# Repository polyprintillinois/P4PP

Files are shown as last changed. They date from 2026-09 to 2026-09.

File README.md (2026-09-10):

<div align="center">
  P4PP Logo
  <h1>P4PP</h1>
  <p><b>Precision 4-Point Probe Controller</b></p>
  <p>Windows GUI for operating a 4-point probe system and logging sheet resistance measurements.</p>
</div>

This repository accompanies **Hwang, Elangovan, Damron, Kwok, Jeon & Diao, "Democratizing Lab Automation through Multi-Agent-Assisted Design and 3D Printing"** (submitted, 2026). Archived release: Zenodo DOI [10.5281/zenodo.22695915](https://doi.org/10.5281/zenodo.22695915). Code is released under the MIT licence; printed-part designs (STL) and documentation may be reused under the same terms with attribution.

---

## Overview

P4PP is the control application for a custom 4-point probe measurement setup.

It provides:

- motion and hardware control through serial communication
- measurement execution (single or multi-cycle)
- live result visualization
- automatic CSV reporting

Target metric: **Sheet Resistance (Rs, Ohm/sq)**.

## Quick Start (1 Minute)

1. Download latest release: https://github.com/polyprintillinois/P4PP/releases/latest
2. In release assets, download `P4PP.zip`.
3. Extract to a stable folder (example: `C:\Tools\P4PP`).
4. Open extracted `P4PP` folder and run `P4PP.exe`.
5. In the app, keep the default `R_set = 681 ohm`, then select `MOCK` and validate `Connect -> Home -> Measure`.

Important:

- Keep the extracted `P4PP` folder structure as-is.
- Do not move `P4PP.exe` outside the `P4PP` folder.

## First run (hello world)

1. For real hardware, flash `firmware/p4pp_firmware/p4pp_firmware.ino` to the Arduino Nano 33 IoT. Connect the 12 V / 60 W adapter (relay coil and stepper drivers) and the USB cable (logic and 3.3 V analog rail).
2. Launch the GUI (`P4PP.zip` from Releases, or `python main.py`) and connect. Without hardware, select `MOCK` in the port list and click **Connect**; this runs the GUI against `src/p4pp/driver/mock_hardware.py`. Click **Initialize**, leave the geometry at **Infinite Sheet**, and click **Measure**. The expected synthetic result is approximately 687 Ω/sq.
3. With real hardware, select the Arduino COM port and click **Connect**. Click **HOME** for both axes (Z probe lift and θ sample rotation), or click **Initialize** to home them in sequence. Each axis should complete a fast switch seek, back-off, and slow re-approach.
4. Insert the 68.1 Ω set resistor (approximately 1 mA), place a reference sample of known sheet resistance (for example, ITO-coated glass), select the sample geometry, and click **Measure**. One delta-mode cycle takes approximately 0.3 s; five cycles are averaged by default (up to 20 may be selected).
5. The reported sheet resistance should fall within `0.90 × R_ref` to `1.10 × R_ref` (the approximately 10% agreement obtained against a commercial four-point-probe system in the paper), with a cycle-to-cycle CV below 0.1%. Re-landing the probe on the same spot should reproduce the value within approximately 2%.
6. Swap in the 681 Ω set resistor (approximately 100 µA) for samples in the kΩ/sq range.

If readings are physically implausible (negative, or identical for forward and reverse polarity), check the DPDT relay wiring: both poles must switch. See the [Analog Wiring Guide](docs/analog_wiring_guide.md).

## Safety

- The probe head descends with approximately 3.3 N total tip force (85 gf × 4) and has sharp tungsten tips. Keep fingers clear of the sample stage while the Z axis is moving, and never reach under the probe head.
- 12 V is present on the driver and relay board; the analog section runs from the 3.3 V rail. Disconnect the adapter before rewiring.
- Do not touch the sample or probe during a measurement cycle. The relay reverses current polarity within each cycle, and contact changes corrupt the reading.
- Handle doped polymer films and dopant solutions (for example, Magic Blue in acetonitrile) with gloves in a fume hood. The instrument itself does not contain solvents.

## App Screenshot

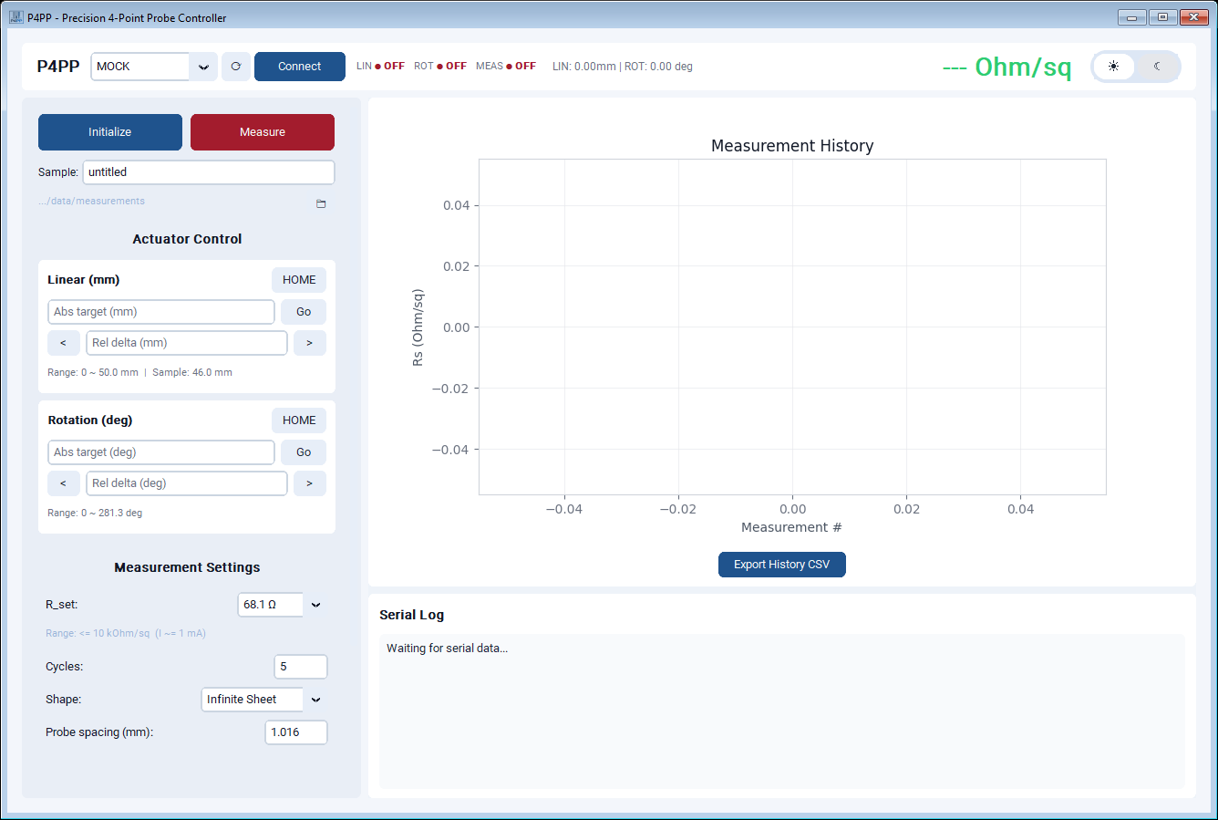
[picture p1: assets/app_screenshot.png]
P4PP main window screenshot


## Highlights

- Live GUI for connect/home/move/measure workflow
- `MOCK` mode for validation without hardware
- Real-time status + graph updates
- Auto-save per-measurement CSV reports
- History CSV export
- Explicit controller state handling

## Hardware Bring-Up (Real Device)

Before using real hardware:

1. Flash firmware: `firmware/p4pp_firmware/p4pp_firmware.ino`
2. Confirm COM port in Windows Device Manager.
3. Complete wiring and calibration checks in docs below.

`R_set` guidance:

- Default startup mode is `681 ohm` (`~0.1 mA`), which is the safer general-purpose option for initial bring-up.
- Switch to `68.1 ohm` (`~1 mA`) for lower-resistance samples such as ITO when you need stronger signal.

Read docs in this order:

1. [4PP Master Guide](docs/4pp_master_guide.md)
2. [Analog Wiring Guide](docs/analog_wiring_guide.md)
3. [Movement Implementation Guide](docs/movement_implementation_guide.md)
4. [App Architecture](docs/app_architecture.md)

## First Real Measurement Checklist

1. Pass full `MOCK` workflow first.
2. Switch to real COM port and connect.
3. Run one low-risk test sample.
4. Confirm graph updates and CSV output in `data/`.

## Troubleshooting

### Serial connection fails

- Recheck COM port in Device Manager.
- Ensure no other application is holding the port.
- Re-test with `MOCK` mode first.

### App does not start (`ModuleNotFoundError: tkinter`)

- Use the official release package (`P4PP.zip`) from Releases.
- If you built locally, use Python 3.11 and rebuild with `P4PP.spec`.

### Measured result stays near `0.00`

- Confirm the Arduino firmware is updated together with the PC app.
- `681 ohm` mode is intended for higher-resistance samples; low-resistance films may require `68.1 ohm`.

### Build/runtime metadata error (`PackageNotFoundError: p4pp`)

- Build with `main.py` as entry script.
- Use the provided `P4PP.spec`.

### Build instability on mixed Python environments

- Build using a clean Python 3.11 virtual environment.
- Clear `PYTHONPATH` before packaging to avoid external site-package contamination.

---

## Developer Notes

### Repository Structure

```text
P4PP/
|- assets/               # logo/icons
|- data/                 # measurement outputs
|- docs/                 # English docs
|- firmware/             # Arduino firmware
|- src/p4pp/             # application source
|- main.py               # app entry point
|- P4PP.spec             # PyInstaller spec
`- setup.py              # package metadata
```

### Local Run

```powershell
py -3.11 -m venv venv
.\venv\Scripts\Activate.ps1
python -m pip install --upgrade pip
pip install -e .
python main.py
```

### Build

```powershell
py -3.11 -m venv build_venv
.\build_venv\Scripts\Activate.ps1
python -m pip install --upgrade pip
python -m pip install pyserial customtkinter matplotlib Pillow pyinstaller
$env:PYTHONPATH = ""
python -m PyInstaller --noconfirm --clean P4PP.spec
```

Output:

- `dist/P4PP/P4PP.exe`
- optional archive: `dist/P4PP.zip`

## Distribution Policy

- `dist/` is **not tracked** in `main` (ignored by `.gitignore`).
- Binaries are distributed via **GitHub Releases assets**.
- `build/` is temporary and can be deleted safely.

## License

P4PP is released under the [MIT License](LICENSE).

Copyright (c) 2026 Changhyun Hwang, Diao Research Group, University of Illinois at Urbana-Champaign.

Validate safety and calibration before production use.

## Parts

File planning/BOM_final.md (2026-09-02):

# Final Bill of Materials (BOM) - P4PP System

This list reflects the final components used to construct the P4PP system and is synchronized with **`P4PP_BOM_Final.csv`**. Item numbers match the `BOM #xx` references used throughout the guides. The 15-item movement list is transcribed from `4pp_movement_BOM_list.xlsx`; the existing switch (#24) and stepper motor (#36) rows were updated in place to avoid duplicates.

## 1. Controller & ADC (Core)

| No. | Qty | Category | Item Name | Notes / Usage |
| :---: | :---: | :--- | :--- | :--- |
| **1** | 1 | Core / Controller | Arduino Nano 33 IoT (3.3V) | Main controller and SPI master |
| **2** | 1 | Core / ADC | ADS1220 24-bit ADC breakout | Precise voltage/current measurement |

## 2. Constant Current Source & Relay Switching

| No. | Qty | Category | Item Name | Notes / Usage |
| :---: | :---: | :--- | :--- | :--- |
| **3** | 1 | Current Source | Adjustable current source IC (TO-92) | LM334 constant current source |
| **4** | 1 | Current Source | Rset for 1.0 mA (68.1 Ω, 0.1%) | General measurements such as ITO |
| **5** | 1 | Current Source | Rset for 100 µA (681 Ω, 0.1%) | Swappable for higher-resistance samples |
| **6** | 1 | Current Sense | Shunt resistor for current monitor (100 Ω, 0.1%) | Current-monitoring shunt |
| **7** | 1 | Current Reversal | DPDT relay, 12 V coil | Delta-mode reversal relay |
| **8** | 1 | Relay Driver | NPN transistor (TO-92) | PN2222A relay driver |
| **9** | 1 | Relay Driver | Flyback diode for relay coil | Relay back-EMF protection |
| **10** | 2 | Relay Driver | Base resistor (1 kΩ) | Base protection and pull-down |

## 3. Probe Head, Input Protection & Connectors

| No. | Qty | Category | Item Name | Notes / Usage |
| :---: | :---: | :--- | :--- | :--- |
| **11** | 1 | ADC Input Protection | BAT54A common-anode diode array | V+/V− protection |
| **12** | 1 | ADC Input Protection | BAT54C common-cathode diode array | Complementary V+/V− protection |
| **13** | 2 | ADC Input Protection | SOT23-to-DIP adapter | SMD diode adapter |
| **18** | 1 | Probe Connector | Black binding post | Probe I/V connection |
| **19** | 1 | Probe Connector | Red binding post | Probe I/V connection |
| **20** | 1 | Probe Connector | Green binding post | Probe I/V connection |
| **21** | 1 | Probe Connector | Blue binding post | Probe I/V connection |
| **50** | 1 | Probe Head | Signatone SP4-40085TFJ | Reused laboratory stock, ~$300–400 (quotation) |

## 4. Main Power, Protection & Filtering

| No. | Qty | Category | Item Name | Notes / Usage |
| :---: | :---: | :--- | :--- | :--- |
| **14** | 1 | Power | 12 V wall adapter, 60 W (12 V/5 A), 2.5 mm | Main power adapter |
| **15** | 1 | Power | Power cord | Adapter power cord |
| **25** | 1 | Power (DC input) | 5.5 mm OD × 2.5 mm ID DC barrel jack | 12 V enclosure input |
| **26** | 1 | Power Protection | Inline ATC/ATO blade-fuse holder | Short-circuit protection |
| **27** | 1 | Power Protection | ATC/ATO blade fuse, 5 A, 32 V | Replaceable fuse |
| **28** | 1 | Stabilizing | 10 Ω, 1%, 0.25 W resistor | 3.3 V low-pass filtering |
| **29** | 1 | Stabilizing | 1 µF, 10%, 16 V ceramic capacitor | Power decoupling |
| **30** | 1 | Stabilizing | 0.1 µF, 10%, 50 V ceramic capacitor | High-frequency filtering |
| **31** | 1 | Power Decoupling | 470 µF, 25 V low-ESR electrolytic capacitor | Motor-driver bulk decoupling |

## 5. Motion Drive Electronics

| No. | Qty | Category | Item Name | Notes / Usage |
| :---: | :---: | :--- | :--- | :--- |
| **33** | 2 | Linear Motion | TMC2209 stepper motor driver | Linear and rotational motor drivers |

## 6. Movement Hardware (15 Source Items)

| No. | Qty | Supplier / SKU | Item Name | Notes / Usage |
| :---: | :---: | :--- | :--- | :--- |
| **24** | 2 | Mouser / V-153-1C25 | Omron snap-action SPDT switch | $5.75 each; homing limit switches |
| **36** | 2 | Stepperonline / 17HS08-1004S | Stepper motor | Linear and rotational axes |
| **37** | 1 | goBILDA / 1309-0016-2005 | sonic hub | Connect rotation motor shaft to sample stage |
| **38** | 2 | McMaster-Carr / 47065t101 | t slotted frame, 1 ft | Structural frame |
| **39** | 1 | McMaster-Carr / 88805K515 | l bracket stock, aluminum, 1 ft | Machine two 6-inch brackets; fixes shaft bores and linear motor |
| **40** | 1 | goBILDA / 4002-0005-0008 | Flexible clamping shaft coupler, 5 mm to 8 mm | Connect linear motor to 8 mm lead screw |
| **41** | 1 | goBILDA / 3501-0804-0250 | 8 mm lead, 4-start lead screw, 250 mm | Linear axis lead screw |
| **42** | 2 | goBILDA / 2100-0008-0250 | 8 mm stainless-steel shaft, 250 mm | Linear-stage stability |
| **43** | 4 | goBILDA / 1310-0016-0008 | 1310 Series Hyper Hub, 8 mm bore | Fix shafts to L-brackets |
| **44** | 1 | goBILDA / 1612-0815-0024 | 8 mm ID linear ball bearing, 2-pack | Shaft bearings |
| **45** | 2 | goBILDA / 1302-0032-0015 | 1302 Series Clamping Hub, 15 mm bore | Fix linear bearings to the 4PP stage |
| **46** | 1 | goBILDA / 3500-0804-1216 | 8 mm lead, 4-start lead-screw barrel nut | Fix lead screw to the 4PP stage |
| **47** | 1 | goBILDA / 1301-0016-0012 | 1301 Series Clamping Hub, 12 mm bore | Fix barrel nut to the 4PP stage |
| **48** | 1 | goBILDA / 1310-0016-5008 | 1310 Series Hyper Hub, 4-start lead-screw bore | Fix lead screw to top L-bracket |
| **49** | 1 | McMaster-Carr / 8975K74 | Multipurpose 6061 aluminum bar, 2 in × 1/2 ft × 0.5 in | 3.5 inches used for stage and probe-head mount |

The 15 source items total **$176.75**, matching the source workbook. This subtotal includes the updated switch (#24) and existing stepper motor (#36).

## 7. Boards, Headers, Wiring & Accessories

| No. | Qty | Category | Item Name | Notes / Usage |
| :---: | :---: | :--- | :--- | :--- |
| **16** | 1 | Headers | Male header, 1×40, 2.54 mm | Arduino mounting and general interconnects |
| **17** | 1 | Headers | Female header, 1×40, 2.54 mm | Swappable Rset sockets and interconnects |
| **22** | 1 | EMI / Noise Control | Ferrite clamp | Motor-cable noise suppression |
| **23** | 1 | Wiring | Shielded 22 AWG wire | Optional V+/V− shielding |
| **32** | 1 | Cables | Micro-USB cable | Arduino Nano-to-PC connection |
| **34** | 1 | Breadboard | Perma-Proto full-sized breadboard PCB | Measurement circuit boards |
| **35** | 3 | Breadboard | Perma-Proto mint-tin-size breadboard PCB | Switching and motor boards |

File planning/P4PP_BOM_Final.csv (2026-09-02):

item # | Category | Item | Qty | Supplier | Supplier_PN | Mfr | Mfr_PN | URL | unit price | total | Notes
1 | Core / Controller | Arduino Nano 33 IoT (3.3V) | 1 | Digi-Key | 1050-ABX00027-ND | Arduino | ABX00027 | https://www.digikey.com/en/products/detail/arduino/ABX00027/10239968 | 23.9 | 23.9
2 | Core / ADC | ADS1220 24-bit ADC breakout | 1 | Digi-Key | 1188-BB-ADS1220-ND | Olimex LTD | BB-ADS1220 | https://www.digikey.com/en/products/detail/olimex-ltd/BB-ADS1220/21662042 | 18.64 | 18.64
3 | Current Source (PoC-simple) | Adjustable current source IC (TO-92) | 1 | Digi-Key | LM334ZNS/NOPB-ND | Texas Instruments | LM334Z/NOPB | https://www.digikey.com/en/products/detail/texas-instruments/LM334Z-NOPB/6215 | 0.637 | 0.637
4 | Current Source (PoC-simple) | Rset for 1.0 mA (68.1?, 0.1%) | 1 | Digi-Key | 1712-YR1B68R1CCCT-ND | TE Connectivity Passive Product | YR1B68R1CC | https://www.digikey.com/en/products/detail/te-connectivity-passive-product/YR1B68R1CC/2390921 | 0.4628 | 0.4628
5 | Current Source (PoC-simple) | Rset for 100 µA (681?, 0.1%) | 1 | Digi-Key | 1712-YR1B681RCCCT-ND | TE Connectivity Passive Product | YR1B681RCC | https://www.digikey.com/en/products/detail/te-connectivity-passive-product/YR1B681RCC/2390920 | 0.4628 | 0.4628
6 | Current Sense (recommended) | Shunt resistor for current monitor (100?, 0.1%) | 1 | Digi-Key | 13-MFP-25BRD52-100RCT-ND | YAGEO | MFP-25BRD52-100R | https://www.digikey.com/en/products/detail/yageo/MFP-25BRD52-100R/2058796 | 0.3272 | 0.3272
7 | Current Reversal (upgrade) | DPDT relay, 12V coil (through-hole) | 1 | Digi-Key | 255-1002-5-ND | Panasonic Electric Works | TQ2-12V | https://www.digikey.com/en/products/detail/panasonic-electric-works/TQ2-12V/251774 | 2.16 | 2.16
8 | Relay Driver | NPN transistor (TO-92) | 1 | Digi-Key | PN2222AFS-ND | Onsemi | PN2222ABU | https://www.digikey.com/en/products/detail/onsemi/pn2222abu/6534 | 0.184 | 0.184
9 | Relay Driver | Flyback diode for relay coil | 1 | Digi-Key | 1N4148FS-ND | Onsemi | 1N4148FS-ND | https://www.digikey.com/en/products/detail/onsemi/1N4148/458603 | 0.41 | 0.41
10 | Relay Driver | Base resistor (1k?, 0.1% optional; 1% OK) | 2 | Digi-Key | A105942CT-ND | TE Connectivity Passive Product | YR1B1K0CC | https://www.digikey.com/en/products/detail/te-connectivity-passive-product/YR1B1K0CC/2390772 | 0.4568 | 0.9136
11 | ADC Input Protection | Diode Array 1 Pair Common Anode 30 V 200mA Surface Mount TO-236-3, SC-59, SOT-23-3 | 1 | Digi-Key | 4878-BAT54ACT-ND | Diotec Semiconductor | BAT54A | https://www.digikey.com/en/products/detail/diotec-semiconductor/BAT54A/13163440 | 0.088 | 0.088
12 | ADC Input Protection | Diode Array 1 Pair Common Cathode 30 V 200mA Surface Mount TO-236-3, SC-59, SOT-23-3 | 1 | Digi-Key | 4878-BAT54CTR-ND | Diotec Semiconductor | BAT54C | https://www.digikey.com/en/products/detail/diotec-semiconductor/BAT54C/13163831 | 0.092 | 0.092
13 | ADC Input Protection | SOT23 TO DIP ADAPTER | 2 | Digi-Key | 1568-00717-ND | SparkFun Electronics | 717 | https://www.digikey.com/en/products/detail/sparkfun-electronics/00717/5318740 | 1.25 | 2.5
14 | Power | 12V wall adapter, 60W (12V/5A), 2.5mm center-positive | 1 | Digi-Key | 1939-1237-ND | GlobTek, Inc. | TR9CE5000LCP-N(R6B) | https://www.digikey.com/en/products/detail/globtek-inc/TR9CE5000LCP-N-R6B/8598040 | 19.24 | 19.24
15 | Power | Power Cord | 1 | Digi-Key | TL868-ND | Eaton Tripp Lite | P006-002-13A | https://www.digikey.com/en/products/detail/eaton-tripp-lite/P006-002-13A/4896253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 | 8.23 | 8.23
16 | Headers | Male header, 1x40, 2.54mm, through-hole | 1 | Digi-Key | HDR100IMP40M-G-V-TH-ND | Chip Quik Inc. | HDR100IMP40M-G-V-TH | https://www.digikey.com/en/products/detail/chip-quik-inc/HDR100IMP40M-G-V-TH/5978197 | 0.69 | 0.69
17 | Headers | Female header, 1x40, 2.54mm, through-hole | 1 | Digi-Key | HDR100IMP40F-G-V-TH-ND | Chip Quik Inc. | HDR100IMP40F-G-V-TH | https://www.digikey.com/en/products/detail/chip-quik-inc/HDR100IMP40F-G-V-TH/5978200 | 1.09 | 1.09
18 | Connectors (Probe I/V) | CONN BIND POST KNURLED BLACK | 1 | Digi-Key | 501-1094-ND | Pomona Electronics | 3760-0 | https://www.digikey.com/en/products/detail/pomona-electronics/3760-0/603401 | 6.29 | 6.29
19 | Connectors (Probe I/V) | Binding Post Connector Standard Knurled Red Tin | 1 | Digi-Key | 501-1095-ND | Pomona Electronics | 3760-2 | https://www.digikey.com/en/products/detail/pomona-electronics/3760-2/603402 | 6.29 | 6.29
20 | Connectors (Probe I/V) | Binding Post Connector Standard Knurled Green Tin | 1 | Digi-Key | 501-1506-ND | Pomona Electronics | 3760-5 | https://www.digikey.com/en/products/detail/pomona-electronics/3760-5/736554 | 6.29 | 6.29
21 | Connectors (Probe I/V) | CONN BIND POST KNURLED BLUE | 1 | Digi-Key | 501-1650-ND | Pomona Electronics | 3760-6 | https://www.digikey.com/en/products/detail/pomona-electronics/3760-6/736555 | 6.29 | 6.29
22 | EMI / Noise control (optional) | Ferrite clamp (snap-on) for motor cable | 1 | Digi-Key | 1934-1375-ND | Fair-Rite | 431167281 | https://www.digikey.com/en/products/filter/ferrite-cores/933 | 1.792 | 1.792
23 | Wiring (optional shield) | shielded wire 22AWG (for V+ / V- lines, optional) | 1 | Digi-Key | 135-94610605000-DS-ND | Belden Inc. | 9461 0605000 | https://www.digikey.com/en/products/detail/belden-inc/9461-0605000/8132459 | 2.9336 | 2.9336
24 | Motion / Limit Switch | SWITCH SNAP ACTION SPDT 15A 250V | 2 | Mouser | 653-V-153-1C25 | Omron Electronics | V-153-1C25 | https://www.mouser.com/en/ProductDetail/Omron-Electronics/V-153-1C25?qs=WOBxwZpV8jWr%252BiSFeM5Nxw%3D%3D | 5.75 | 11.5 | Linear and rotational homing limit switches
25 | Power (DC input) | DC barrel jack, 5.5mm OD x 2.5mm ID, PCB right-angle, through-hole | 1 | Digi-Key | SC1863-ND | Switchcraft Inc. | RAPC712BK | https://www.digikey.com/en/products/detail/switchcraft-inc/RAPC712BK/1288493 | 3.09 | 3.09
26 | Power Protection | Inline blade fuse holder (ATC/ATO), splashproof cover, wire leads | 1 | Digi-Key | F3209-ND | Littelfuse/Commercial Vehicle Products | FHAC0001ZXJ | https://www.digikey.com/en/products/detail/littelfuse-commercial-vehicle-products/FHAC0001ZXJ/2004062 | 5.33 | 5.33
27 | Power Protection | ATC/ATO blade fuse, 5A, 32V | 1 | Digi-Key | 0287005.U-ND | Littelfuse Inc. | 0287005.U | https://www.digikey.com/en/products/detail/littelfuse-inc/0287005.U/3996899 | 0.332 | 0.332
28 | stabilizing | 10 Ohms ±1% 0.25W, 1/4W Through Hole Resistor Axial Metal Film | 1 | Digi-Key | 13-MFR-25FTF52-10RCT-ND | YAGEO | MFR-25FTF52-10R | https://www.digikey.com/en/products/detail/yageo/MFR-25FTF52-10R/9140488?utm_source=chatgpt.com | 0.0312 | 0.0312
29 | stabilizing | 1 µF ±10% 16V Ceramic Capacitor X7R Radial | 1 | Digi-Key | 445-FK24X7R1C105KN000-ND | TDK Corporation | FK24X7R1C105KN000 | https://www.digikey.com/en/products/detail/tdk-corporation/fk24x7r1c105kn000/1008884 | 0.1738 | 0.1738
30 | stabilizing | 0.1 µF ±10% 50V Ceramic Capacitor X7R Radial | 1 | Digi-Key | 490-9144-1-ND | Murata Electronics | RDER71H104K0M1H03A | https://www.digikey.com/en/products/detail/murata-electronics/RDER71H104K0M1H03A/4772306 | 0.2084 | 0.2084
31 | Power Decoupling | Bulk electrolytic capacitor, low ESR, 470uF 25V radial | 1 | Digi-Key | P14418-ND | Panasonic Electronic Components | EEU-FR1E471L | https://www.digikey.com/en/products/detail/panasonic-electronic-components/EEU-FR1E471L/2433552 | 0.592 | 0.592
32 | Cables | Micro-USB cable (Nano 33 IoT to PC) | 1 | Adafruit | Product ID 2185 | Adafruit | 2185 | https://www.adafruit.com/product/2185 | 4.95 | 4.95
33 | Linear Motion | TMC2209 Stepper Motor Driver | 2 | Adafruit | Product ID 6121 | Adafruit | 6121 | https://www.adafruit.com/product/6121 | 8.95 | 17.9
34 | Breadboard | Perma-Proto Full-sized Breadboard PCB - Single | 1 | Adafruit | Product ID 1606 | Adafruit | 1606 | https://www.adafruit.com/product/1606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 | 10.95 | 10.95
35 | Breadboard | Perma-Proto Mint Tin Size Breadboard PCB | 3 | Adafruit | Product ID 723 | Adafruit | 723 | https://www.adafruit.com/product/723 | 5.95 | 17.85
36 | Linear Motion | Stepper Motor | 2 | Stepperonline | 17HS08-1004S | Stepperonline | 17HS08-1004S | https://www.omc-stepperonline.com/nema-17-bipolar-1-8deg-16ncm-22-6oz-in-1a-3-7v-42x42x20mm-4-wires-17hs08-1004s | 7.99 | 15.98
37 | Motion / Rotation | sonic hub | 1 | goBILDA | 1309-0016-2005 | goBILDA | 1309-0016-2005 | https://www.gobilda.com/1309-series-sonic-hub-5mm-hex-bore/ | 7.99 | 7.99 | connect rotation motor shaft to sample stage
38 | Motion / Frame | t slotted frame, 1 ft | 2 | McMaster-Carr | 47065t101 | McMaster-Carr | 47065t101 | https://www.mcmaster.com/47065t101/ | 8.37 | 16.74
39 | Motion / Frame | l bracket - machine using 88805K515 l bracket aluminum 1ft | 1 | McMaster-Carr | 88805K515 | McMaster-Carr | 88805K515 | https://www.mcmaster.com/88805K515/ | 10.18 | 10.18 | fix shaft bores and linear motor. 1/2 price as we only need 6 inch for two brackets
40 | Motion / Linear | 4002 Series Flexible Clamping Shaft Coupler (5mm Round Bore to 8mm Round Bore) | 1 | goBILDA | 4002-0005-0008 | goBILDA | 4002-0005-0008 | https://www.gobilda.com/4002-series-flexible-clamping-shaft-coupler-5mm-round-bore-to-8mm-round-bore/ | 6.99 | 6.99 | connect linear motor to 8mm lead screw
41 | Motion / Linear | 3501 Series Lead Screw (8mm Lead, 4 Start, 250mm Length) | 1 | goBILDA | 3501-0804-0250 | goBILDA | 3501-0804-0250 | https://www.gobilda.com/3501-series-lead-screw-8mm-lead-4-start-250mm-length/ | 8.99 | 8.99 | lead screw for linear motor
42 | Motion / Linear | 8mm Shaft (Stainless Steel, 250mm Length) | 2 | goBILDA | 2100-0008-0250 | goBILDA | 2100-0008-0250 | https://www.gobilda.com/2100-series-stainless-steel-round-shaft-8mm-diameter-250mm-length/ | 5.79 | 11.58 | 8mm shaft for stability
43 | Motion / Linear | 1310 Series Hyper Hub (8mm Bore) | 4 | goBILDA | 1310-0016-0008 | goBILDA | 1310-0016-0008 | https://www.gobilda.com/1310-series-hyper-hub-8mm-bore/ | 7.99 | 31.96 | fix shafts to l brackets
44 | Motion / Linear | 8mm ID Linear Ball Bearing (15mm OD, 24mm Length) - 2 Pack | 1 | goBILDA | 1612-0815-0024 | goBILDA | 1612-0815-0024 | https://www.gobilda.com/8mm-id-linear-ball-bearing-15mm-od-24mm-length-2-pack/ | 4.99 | 4.99 | linear ball bearing for shaft
45 | Motion / Linear | 1302 Series Clamping Hub (15mm Bore) | 2 | goBILDA | 1302-0032-0015 | goBILDA | 1302-0032-0015 | https://www.gobilda.com/1302-series-clamping-hub-15mm-bore/ | 7.99 | 15.98 | clamps fixing linear ball bearings to 4pp stage
46 | Motion / Linear | 3500 Series Lead Screw Barrel Nut (8mm Lead, 4 Start, 12mm OD, 16mm Length) | 1 | goBILDA | 3500-0804-1216 | goBILDA | 3500-0804-1216 | https://www.gobilda.com/3500-series-lead-screw-barrel-nut-8mm-lead-4-start-12mm-od-16mm-length/ | 4.99 | 4.99 | barrel nut fixing lead screw with 4pp stage
47 | Motion / Linear | 1301 Series Clamping Hub (12mm Bore) | 1 | goBILDA | 1301-0016-0012 | goBILDA | 1301-0016-0012 | https://www.gobilda.com/1301-series-clamping-hub-12mm-bore/ | 6.99 | 6.99 | clamp fixing lead screw barrel nut with 4pp stage
48 | Motion / Linear | 1310 Series Hyper Hub (4 Start, 8mm Lead Screw Bore) | 1 | goBILDA | 1310-0016-5008 | goBILDA | 1310-0016-5008 | https://www.gobilda.com/1310-series-hyper-hub-4-start-8mm-lead-screw-bore/ | 10.99 | 10.99 | fix lead screw to top l bracket
49 | Motion / Stage | Multipurpose 6061 Aluminum Bar 2 inch x 1/2 ft x 0.5 inch | 1 | McMaster-Carr | 8975K74 | McMaster-Carr | 8975K74 | https://www.mcmaster.com/8975K74/ | 10.9 | 10.9 | only need 3.5 inch out of 6 inches for 4pp stage and 4pp head mount : 10.9*3.5/6=6.36
50 | Probe Head | Signatone SP4-40085TFJ | 1 | Signatone | SP4-40085TFJ | Signatone | SP4-40085TFJ | https://www.signatone.com/application/four-point-probe-head/ | 350 | 350 | reused laboratory stock, ~$300–400 (quotation)

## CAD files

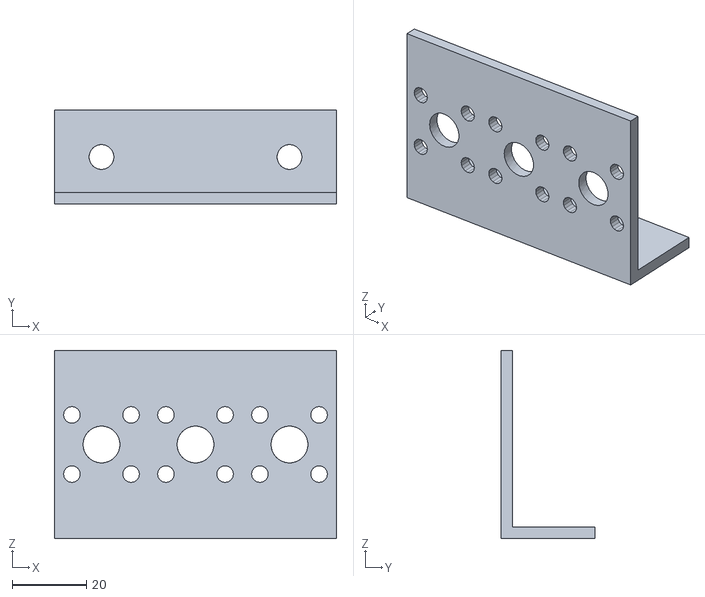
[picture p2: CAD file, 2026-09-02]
parts/l-bracket_top.stl
76.2 x 25.4 x 50.8

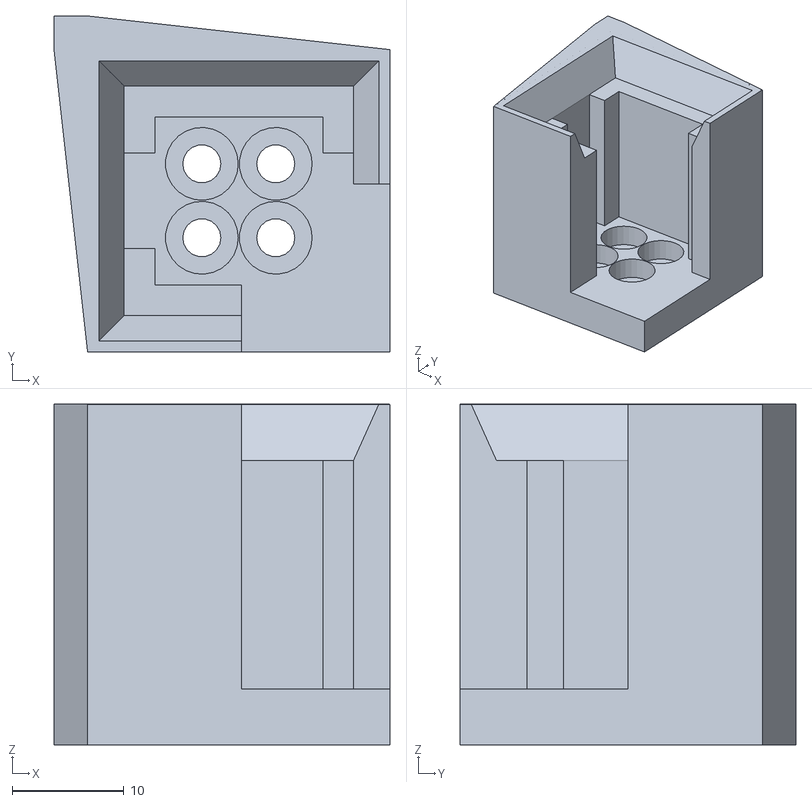
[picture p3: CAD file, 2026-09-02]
parts/film_holder.stl
30.0 x 30.0 x 30.4

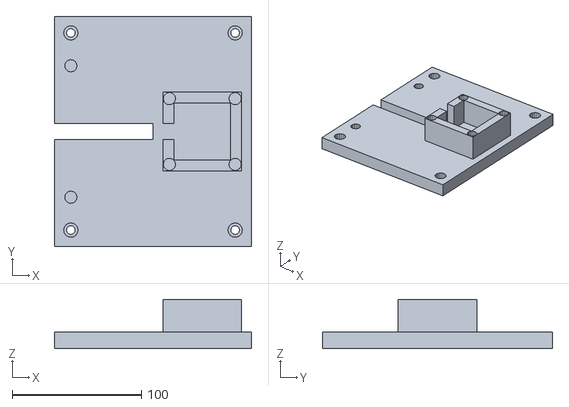
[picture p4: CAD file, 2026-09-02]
parts/baseplate.stl
152.4 x 177.8 x 38.1

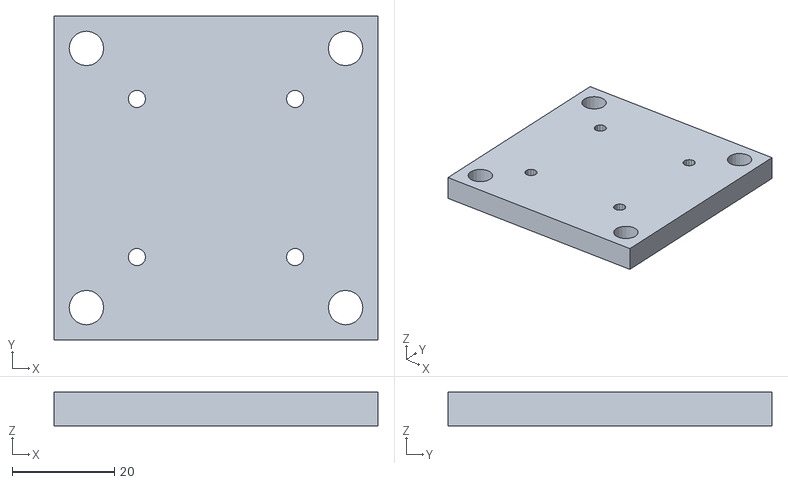
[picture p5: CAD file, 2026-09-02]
parts/rotation_motor_cover.stl
63.5 x 63.5 x 6.60

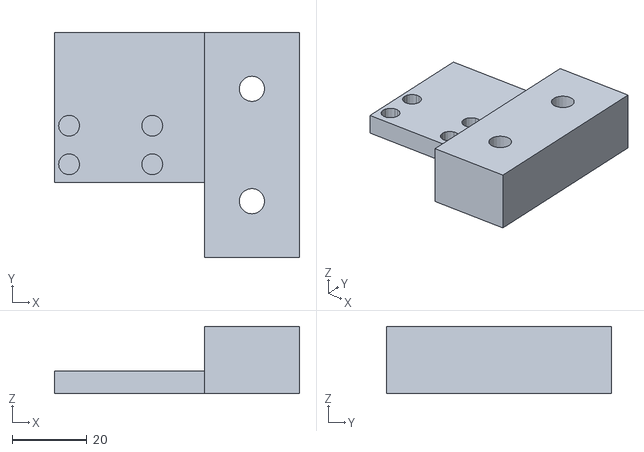
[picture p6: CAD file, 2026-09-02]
parts/switch_holder_top.stl
65.4 x 60.0 x 18.0

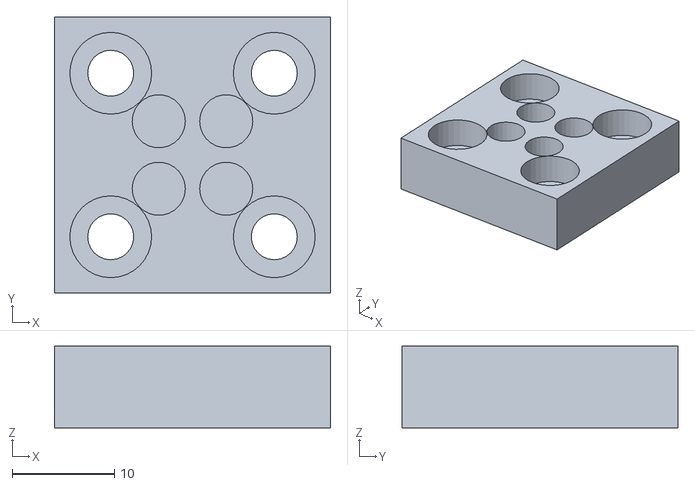
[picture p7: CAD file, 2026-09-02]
parts/film_holder_support.stl
27.0 x 27.0 x 8.00

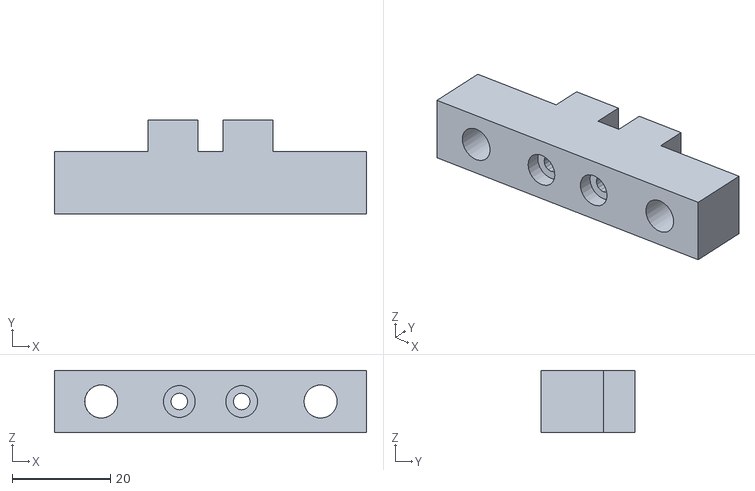
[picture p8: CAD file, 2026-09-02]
parts/4pp_head_mount.stl
63.5 x 19.1 x 12.7

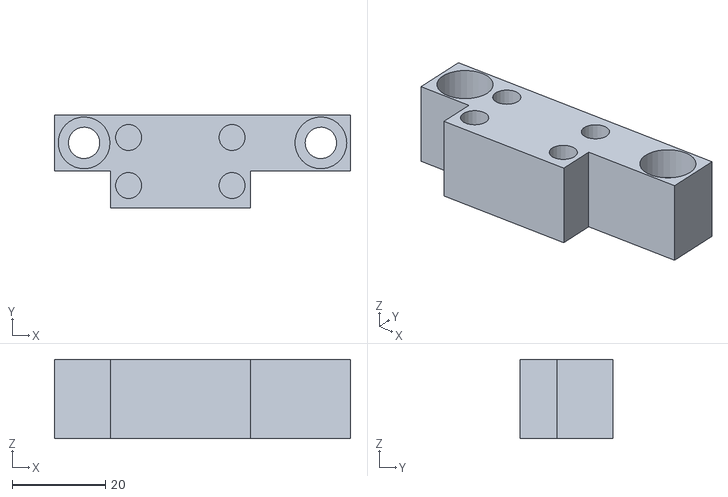
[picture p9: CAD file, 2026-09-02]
parts/rotation_switch_holder.stl
63.5 x 20.0 x 17.0

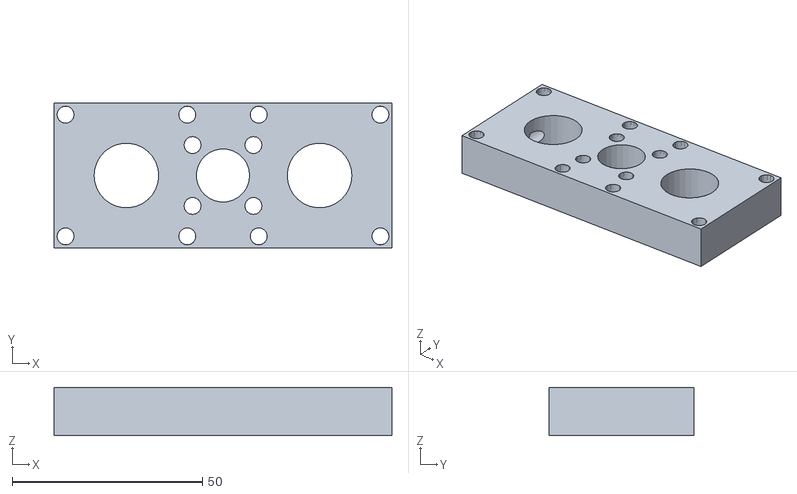
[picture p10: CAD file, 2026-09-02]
parts/4pp_stage.stl
88.9 x 38.1 x 12.7

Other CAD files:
parts/l-bracket_bottom.stl

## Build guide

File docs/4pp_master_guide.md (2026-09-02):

# 4-Point Probe Surface Resistance Measurement System Comprehensive Guide

> **Version**: 1.1 | **Date**: 2026-02-03 | **BOM**: P4PP_BOM_Final.csv

---

## 📋 Table of Contents

1. [System Overview](#1-system-overview)
2. [Core Design Principles](#2-core-design-principles)
3. [BOM Details](#3-bom-details)
4. [Detailed Circuit Design](#4-detailed-circuit-design)
5. [Stripboard Layout Overview](#5-stripboard-layout-overview)
6. [Assembly Sequence (Bring-up)](#6-assembly-sequence-bring-up)
7. [Software Implementation](#7-software-implementation)
8. [Verification and Debugging](#8-verification-and-debugging)
9. [Measurement Formulas & Correction](#9-measurement-formulas--correction)
10. [Checklist](#10-checklist)

---

## 1. System Overview

### 1.1 Objective

Implement a PoC system to measure the **Sheet Resistance (Rs, Ω/□)** of ITO and thin films using a Signatone SP4-40085TFJ 4-point probe head.

### 1.2 Scope

| INCLUDED | EXCLUDED |
|---|---|
| Power (12V + USB) | Stepper Motors/Drivers |
| Constant Curr Src (LM334)| Limit Switches |
| Voltage Msmt (ADS1220)| Motor Cabling |
| Input Protect (Clamps)| |
| Current Reversal (Relays)| |
| **(IN BOM) Linear Motion**| **Tier 2: Automation (Excluded in PoC)**|

> [!CAUTION]
> **Mandatory Probe Usage Precautions**
> - Always **verify sample levelness** and lower the probe **perfectly vertically**.
> - Signatone probe tips are extremely sharp and sensitive; lowering them at an angle risks severe damage.
> - **Probe Pressure Spec**: The model `085` denotes **85g per tip**.
>   - Total load across 4 tips: Approx. **340g**
>   - The Z-axis mechanism must support this load and descend smoothly without overshoot.
>   - Absolute prohibition against horizontal dragging! It directly destroys tip lifespan.

### 1.3 Block Diagram (3-Board Modular Architecture)

```
┌─────────────────────────────────────────────────────────────────────────┐
│                        System 3-Board Architecture                      │
├─────────────────────────────────────────────────────────────────────────┤
│                                                                         │
│  ┌──────────┐    USB     ┌──────────────────┐                           │
│  │    PC    │◄─────────►│ [Board A]         │                           │
│  │ (Serial) │            │ Arduino Nano      │                           │
│  └──────────┘            │ 33 IoT (3.3V)     │                           │
│                          └────────┬──────────┘                           │
│                                   │ SPI / GPIO                           │
│                     ┌─────────────┴─────────────┐                        │
│                     ▼                           ▼                        │
│  ┌─────────────────────────────┐  ┌─────────────────────────────┐        │
│  │ [Board B]                   │  │ [Board C]                   │        │
│  │ Analog Precision Board      │  │ High-Voltage (12V) Switch   │        │
│  │  ┌─────────────────────┐   │  │  ┌─────────────────────┐   │        │
│  │  │      ADS1220        │   │  │  │   DPDT Relay         │   │        │
│  │  │  (24-bit ΔΣ ADC)    │   │  │  │ (Current Reversal)   │   │        │
│  │  └──────────┬──────────┘   │  │  │ Pole A: Source Swap  │   │        │
│  │             │              │  │  │ Pole B: Return Swap  │   │        │
│  │  ┌──────────┴──────────┐   │  │  └──────────┬──────────┘   │        │
│  │  │ Input Protection    │   │  │             │              │        │
│  │  │ (1kΩ + BAT54A/C)    │   │  │  ┌──────────┴──────────┐   │        │
│  │  └──────────┬──────────┘   │  │  │ PN2222A + 1N4148     │   │        │
│  │             │              │  │  │ (Relay Driver)       │   │        │
│  │  ┌──────────┴──────────┐   │  │  └─────────────────────┘   │        │
│  │  │ LM334 Source        │   │  │                           │        │
│  │  │ + 100Ω Shunt        │   │  │ ⚠️ Isolated 12V Power!    │        │
│  │  └──────────┬──────────┘   │  │                           │        │
│  └─────────────┼─────────────┘  └─────────────┬─────────────┘        │
│                │ (1mA Supply)                 │                          │
│                └──────────────────────────────┘                          │
│                               │                                          │
│                               ▼                                          │
│  ┌─────────────────────────────────────────────────────────────┐         │
│  │                    Panel Binding Posts                      │         │
│  │              [I+] [V+] [V-] [I-]                            │         │
│  └─────────────────────────────────────────────────────────────┘         │
│                              │                                           │
│                              ▼                                           │
│                    ┌─────────────────┐                                   │
│                    │  Signatone 4PP  │                                   │
│                    │    Probe Head   │                                   │
│                    └─────────────────┘                                   │
│                              ▼                                           │
│                    ┌─────────────────┐                                   │
│                    │   ITO Sample    │                                   │
│                    └─────────────────┘                                   │
└─────────────────────────────────────────────────────────────────────────┘
```

### 1.4 Core Module Descriptions

| Module | Function | Key Parts |
|:---:|---|---|
| **MCU** | Master control, PC comms, ADC data acqusition | Arduino Nano 33 IoT |
| **ADS1220** | Precision voltage read (24-bit). Reads microvolts | ADS1220 (TI) |
| **Input Protection** | Guards delicate ADC from overvoltage/ESD | BAT54S (Diode), 1kΩ |
| **LM334 Current Src** | Injects constant current (1mA/100µA) | LM334, Rset, Shunt |
| **DPDT Relay** | Physically swaps current direction for Delta Mode | Panasonic TQ2-12V |
| **Relay Driver** | Drives 12V relay using 3.3V Arduino signal | PN2222A (Transistor) |
| **Power Filter** | Filters noise out of power lines (Clean 3.3V) | 10Ω, 1µF, 0.1µF |

---

## 2. Core Design Principles

> [!IMPORTANT]
> The following 5 principles MUST be strictly adhered to for accurate measurements.

### 2.1 Keep ADC Inputs Within Rails

```
ADS1220 Safe Input Range (when PGA is bypassed):
AVSS − 0.1V  ~  AVDD + 0.1V
   ↓              ↓
 -0.1V          3.4V  (Assuming 3.3V supply)
```

**Solution**: Tie the constant current source to the 3.3V rail → Keeps sample potential within 0~3.3V.

### 2.2 Use Actual Measured Current, Not Assumed Value

> [!CAUTION]
> The LM334 has **temperature dependency (+0.33%/°C)**, meaning current drifts.
> You must physically measure the injected current using the 100Ω shunt.

```
I_actual = V_shunt / 100Ω
R_sample = V_sense / I_actual  ← The only way to guarantee accuracy.
```

### 2.3 Eliminate Offsets via Current Reversal (Delta Mode)

This is the **most effective method** for canceling Thermal EMF and ADC offsets:

```
1. Inject Forward Curr → (Wait for settle) → Measure V_fwd
2. Swap Curr Dir via Relay → (Wait for settle) → Measure V_rev
3. V_corrected = (V_fwd - V_rev) / 2
4. Firmware: Rs∞ = (π / ln 2) × (V_corrected / I_actual)
5. Host GUI: Rs = F × Rs∞
```

> [!TIP]
> **Settle Time**
> - Recommend waiting **100~300ms** after relay switching.
> - Discarding the first 1~2 samples right after switching stabilizes averages.

### 2.4 Modular Physical Board Separation (3-Board System)

To maximize noise isolation and maintainability, the system is wholly separated into **three physically distinct boards**.

| Board Name | Role | Circuits Included | Power Used |
|---|---|---|---|
| **Board A** | Brain/Controller | Arduino Nano 33 IoT | 5V (USB) → Outputs 3.3V |
| **Board B** | Analog Baseboard | RC filter, ADS1220, LM334, BAT54 | 3.3V (From Board A) |
| **Board C** | Switch/Relay Board | DPDT Relay, PN2222A, Flyback | 12V (Separate Wall Adapter) |

| **If Operating Motors** | - | **Must turn Motor Driver EN=OFF during measurements (Crucial)** |
 
 → **Physical isolation is absolute**. Only essential interface wires cross boundaries.

### 2.5 LM334 Headroom limits (Dropout Warning)

> [!WARNING]
> **Check this when measuring high-resistance samples!**
> 
> Due to the 3.3V power ceiling, if the sample resistance gets too high (**several kΩ or more**), the LM334 cannot maintain its target current (Dropout).

```
LM334 Operating Condition:
  V_headroom = V_supply - V_sample - V_shunt - V_LM334(min)
             = 3.3V - (I × R_sample) - (I × 100Ω) - 0.9V

  ↓ If R_sample grows too large ↓
  V_headroom < 0 → LM334 Dropout → I_actual plummets!
```

**Software monitoring required**:
- Calculate `I_actual = V_shunt / 100 ohm` every cycle.
- Output warnings if current drops by **10% or more** against target.

**Estimated operating guidance**:
- `68.1 ohm Rset` (`~1 mA`): best for lower-resistance samples, but dropout starts sooner.
- `681 ohm Rset` (`~100 uA`, default bring-up mode): safer for higher-resistance samples, but produces a smaller sense voltage on low-resistance films.

**Estimated Limits (at 1mA)**:
```
R_sample_max ~= (3.3V - 0.1V_shunt - 0.9V_LM) / 1mA ~= 2.3kOhm
```

### 2.6 Star Ground Topology

```
                    ┌─────────────────┐
                    │ Arduino GND Pin │ ← Head Station (Star Point)
                    └────────┬────────┘
                             │
            ┌────────────────┼────────────────┐
            │                │                │
            ▼                ▼                ▼
      ┌──────────┐    ┌──────────┐    ┌──────────┐
      │ ADC AGND │    │  3V3_A   │    │ 12V GND  │
      │(Closest) │    │ Decoup.  │    │(Farthest)│
      └──────────┘    └──────────┘    └──────────┘
```

---

## 3. BOM Details (Refer to Master CSV)

> Please refer to the final `BOM_final.md` document for the detailed, synchronized BOM list. All component numbering references `BOM #N` match that finalized file.

---

## 4. Detailed Circuit Design

### 4.1 Power Filter (Generating 3V3_A)

```
Arduino 3V3 ──┬── 3V3_DIG
              │
             10Ω
              │
              ├── 3V3_A ──┬── ADS1220 AVDD/VDD
              │           │
             0.1µF       1µF
              │           │
              └─────┬─────┘
                    │
                  AGND
```

### 4.2 ADC Input Protection Circuit

```
                        3V3_A
                          │
                     ┌────┴────┐
                     │ BAT54C  │
                     │ pin3    │
                     └────┬────┘
                    pin1  │  pin2
                      │   │   │
   V+ ──── 1kΩ ───────┴───┼───┴─────── 1kΩ ──── V-
   Post                   │                     Post
                          │
              ┌───────────┴───────────┐
              │                       │
          IN0_NODE               IN1_NODE
              │                       │
              ▼                       ▼
          ADS1220                 ADS1220
           AIN0                    AIN1
              │                       │
              │     ┌────┬────┐       │
              └─────┤pin1│pin2├───────┘
                    │ BAT54A  │
                    └────┬────┘
                         │ pin3
                         │
                       AGND
```

### 4.3 Constant Current Source (LM334)

```
       3V3_A
         │
         ▼
    ┌─────────┐
    │  LM334  │
    │         │
    │ V+   R  ├──── Rset (68.1Ω or 681Ω)
    │         │         │
    │    V-   ├─────────┘
    └────┬────┘
         │
        100Ω (Shunt) ← V_shunt measurement node
         │
         ▼
    SHUNT_LO (Current output)
```

> [!CAUTION]
> **Crucial DPDT Wiring Correction**
> 
> A DPDT must utilize **BOTH Poles (both COMs)** to successfully reverse the current flow!
> You must cross-swap **Pole A** (Source side) and **Pole B** (Return side) simultaneously.

### 4.4 DPDT Current Reversal Circuit (Critical!)

```
              ┌─────────────────────────────────────────────┐
              │              DPDT Relay (TQ2-12V)           │
              │                                             │
              │   Pole A (Source Side)      Pole B (Return) │
              │   ┌───────────┐        ┌───────────┐        │
              │   │           │        │           │        │
   SHUNT_LO ──┼──►│   COM_A   │        │   COM_B   │◄───AGND│
              │   │     │     │        │     │     │        │
              │   │  ┌──┴──┐  │        │  ┌──┴──┐  │        │
              │   │ NC_A  NO_A│        │ NC_B  NO_B│        │
              │   │  │     │  │        │  │     │  │        │
              │   └──┼─────┼──┘        └──┼─────┼──┘        │
              └─────┼─────┼──────────────┼─────┼────────────┘
                    │     │              │     │
                    │     └──────────────┼─────┼──► I- Post
                    │                    │     │
                    └────────────────────┼─────┘
                                         │
                                         ▼
                                       I+ Post
```

**Relay Wiring (Orthodox Setup)**:

| Pole | Pin | Connection |
|---|-----|---|
| **A** | COM_A | SHUNT_LO (LM334 Output, post-shunt) |
| **A** | NC_A | I+ Post (Red) |
| **A** | NO_A | I- Post (Black) |
| **B** | COM_B | AGND (Current Return Route) |
| **B** | NC_B | I- Post (Black) |
| **B** | NO_B | I+ Post (Red) |

**Operational Principle**:
- **Relay OFF (NC Contacts)**: SHUNT_LO→I+, AGND→I- → **Forward Current**
- **Relay ON (NO Contacts)**: SHUNT_LO→I-, AGND→I+ → **Reverse Current**

### 4.5 Relay Driver Circuit

```
Arduino ──── 1kΩ ────┬──── PN2222A Base
  GPIO               │
                     │      ┌────────┐
                    10kΩ    │ DPDT   │
                     │      │ Relay  │
                   GND      │  Coil  │
                            └───┬────┘
                                │
                     ┌──────────┼──────────┐
                     │          │          │
               ┌─────┴─────┐  0.1µF  ┌─────┴─────┐
               │  1N4148   │   │     │  Optional │
               │ (Flyback) │   │     │ Snubber   │
               └─────┬─────┘   │     └───────────┘
                     │         │
        PN2222A ─────┴─────────┘
        Collector               │
                               12V
        Emitter ─────── 12V GND
```

### 4.6 Shunt Current Monitor (ADS1220 2nd Channel)

```
LM334 Output ──── Shunt 100Ω ──┬──── To Relay
                             │
              ┌──────────────┴──────────────┐
              │                              │
          Shunt+                         Shunt-
              │                              │
             1kΩ                            1kΩ
              │                              │
              ▼                              ▼
          ADS1220                        ADS1220
           AIN2                           AIN3
```

---

### 4.7 12V Input Protection (Power Protection)

> [!WARNING]
> Protecting the 12V line is mandatory! Relay/Motor spikes can cascade and damage the ADC.

```
       DC Barrel Jack (#25)                To Stripboard #2
            │                                  │
            ▼                                  ▼
  ┌──────────────────────────────────────────────────────┐
  │                                                      │
  │  12V+  ────[FUSE #26+#27]──── 5A ────┬── 12V_FUSED   │
  │    IN                                │               │
  │                           ┌──────────┴──────────┐    │
  │                           │     SMBJ15A         │    │
  │                           │  (TVS Unidir)       │    │
  │                           │  Cathode → 12V      │    │
  │                           │  Anode → GND        │    │
  │                           └──────────┬──────────┘    │
  │                                      │               │
  │  GND  ───────────────────────────────┴── 12V_GND    │
  │                                                      │
  └──────────────────────────────────────────────────────┘
```

---

## 5. Stripboard Layout Overview

> [!NOTE]
> For highly detailed step-by-step soldering and wiring instructions for the Analog (Board B, C) section, refer to **[`analog_wiring_guide.md`](./analog_wiring_guide.md)**.
> For the Stepper Motor and logic details (Board D), refer to **[`movement_implementation_guide.md`](./movement_implementation_guide.md)**.

> [!WARNING]
> **Leakage Current Mitigation**
> - The IN0/IN1 strips (V+/V-) MUST be cleaned with flux remover to maximize insulation resistance.
> - **Even nA of leakage current** will cause massive mV measurement errors.
> - **Flux cleaning is mandatory!** Use IPA (Isopropyl Alcohol) and a brush after soldering.

---

### 5.6 Physical Topology Overview

```
┌─────────────────────────────────────────────────────────────────────────┐
│                      Metal Enclosure (EMI Shield)                       │
│  ┌───────────────────────────────────────────────────────────────────┐  │
│  │                                                                   │  │
│  │   ┌──────────────────┐               ┌──────────────────┐         │  │
│  │   │   [Board B]      │ ◀──ISOLATION──▶ │   [Board C]      │         │  │
│  │   │ Analog/ADC (3.3V)│               │ Relay Drv (12V)  │         │  │
│  │   │  ┌────────────┐  │               │  ┌────────────┐  │         │  │
│  │   │  │  ADS1220   │  │               │  │DPDT Relay  │  │         │  │
│  │   │  └────────────┘  │               │  └────────────┘  │         │  │
│  │   └────────▲─────────┘               └────────▲─────────┘         │  │
│  │            │ SPI cable (7-wire)                 │ Ctrl wire (2)       │  │
│  │            │                                  │                   │  │
│  │            └─────────┬──────────────┬─────────┘                   │  │
│  │                      ▼              ▼                             │  │
│  │                   ┌────────────────────┐                          │  │
│  │                   │     [Board A]      │                          │  │
│  │                   │ Arduino Nano 33 IoT│                          │  │
│  │                   └────────────────────┘                          │  │
│  │                                                                   │  │
│  └───────────────────────────────────────────────────────────────────┘  │
│                                                                         │
│  ┌─────────────────────────────────────────────────────────────────┐    │
│  │                     Panel Binding Posts                         │    │
│  │                                                                 │    │
│  │      🔴 I+      🔵 V+      🟢 V-      ⚫ I-                     │    │
│  │     (Red)     (Blue)    (Green)   (Black)                       │    │
│  └─────────────────────────────────────────────────────────────────┘    │
│                                                                         │
│  Enclosure Case → Tied to AGND (At exactly ONE point)                   │
└─────────────────────────────────────────────────────────────────────────┘
```

---

## 6. Assembly Sequence (Bring-up)

Go to **`analog_wiring_guide.md`** and follow the 7 sequential guide steps listed in that document.

---

## 7. Software Implementation

### 7.1 Recommended ADS1220 Settings

```cpp
// ADS1220 Register Setup
// Config Register 0
//   MUX = AIN0/AIN1 (Differential)
//   GAIN = 1 (PGA bypass) → Circumvents VCM restrictions, simplifies circuit.
//   PGA_BYPASS = 1 (Maximizes input headroom)
byte config0 = 0b00000001; // MUX=00, GAIN=000, PGA_BYPASS=1

// Config Register 1
//   - DR[2:0] = 000 → 20 SPS (Normal mode)
//   - MODE[1:0] = 00 → Normal mode  
//   - CM = 1 → Continuous conversion
byte config1 = 0b00000100;

// Config Register 2
//   VREF=00 (Internal 2.048V) ← Recommended for PoC!
byte config2 = 0b00010000; 

// Config Register 3
byte config3 = 0b00000000;
```

### 7.2 Delta Mode Reversal Routine

```cpp
struct Measurement {
  float V_corrected;
  float I_actual;
  float R_sample;
  float Rs;
};

Measurement measureWithReversal() {
  Measurement m;
  
  // 1. Forward Current
  digitalWrite(RELAY_PIN, LOW);
  delay(500);  // Settle time
  
  float V_fwd = readVoltage(0x00);  // V sense
  float V_shunt_fwd = readVoltage(0x30);  // Shunt
  
  // 2. Reverse Current
  digitalWrite(RELAY_PIN, HIGH);
  delay(500);  // Settle time
  
  float V_rev = readVoltage(0x00);  // V sense
  float V_shunt_rev = readVoltage(0x30);  // Shunt
  
  // 3. Math
  m.V_corrected = (V_fwd - V_rev) / 2.0;
  
  // Average the current (More accurate)
  float I_fwd = V_shunt_fwd / SHUNT_R;
  float I_rev = abs(V_shunt_rev) / SHUNT_R; 
  m.I_actual = (I_fwd + I_rev) / 2.0;
  
  m.R_sample = m.V_corrected / m.I_actual;
  
  // Report the infinite-sheet value. The host GUI applies finite-sample F.
  m.Rs = (PI / log(2.0)) * m.R_sample;
  
  // 4. Return relay to default
  digitalWrite(RELAY_PIN, LOW);
  
  return m;
}
```

---

## 8. Verification and Debugging

### 8.1 Common Problems & Solutions

| Symptom | Cause | Solution |
|---|---|---|
| ADS1220 values jump wildly| Lack of decoupling, Gnd Loop | Add 0.1µF, verify Star Ground |
| Current wildly deviates | Wrong Rset, LM334 blown | Check Rset, replace LM334 |
| V sense clips at rail | Clamp activation, Overvoltage | Check contact, lower the current |
| Rs changes vs varied current | Non-ohmic contact | Increase pressure, clean tips |
| Values drift slowly | Thermal EMF buildup | Use Delta Mode Reversal, let settle |
| Noise when switching relay| 12V/3.3V coupling | Full physical separation, wire routing |

---

## 9. Measurement Formulas & Correction

### 9.1 Basic Math

```
Current-reversal voltage:
  ΔV = (V_fwd - V_rev) / 2

Measured resistance ratio:
  R = ΔV / I
```

The firmware reports the infinite-sheet value

`Rs∞ = (π / ln 2) · (ΔV / I) = 4.532 · (ΔV / I)`.

The host GUI applies the finite-sample correction:

`Rs = F · Rs∞`,

where `F` is the Smits geometric factor (`F = 0.9812` for the 20 × 20 mm,
`s = 1.016 mm` configuration).

### 9.2 Current Reversal Correction (Delta Mode)

```
V_corrected = (V_fwd - V_rev) / 2

Benefits:
  - Eliminates ADC offset
  - Eliminates Thermal EMF voltages
  - Compensates for contact asymmetry
```

### 9.3 Finite-Sample Geometric Factor

> [!WARNING]
> The infinite-sheet value `Rs∞` is not the final result for a finite sample.
> Apply the geometric factor exactly once in the host GUI.

```
Probe Spacing: s = 40 mil = 1.016 mm
Square sample: d = 20 mm
d/s = 20 / 1.016 ≈ 19.685
Smits factor: F ≈ 0.9812
```

The firmware's `4.532` multiplier already converts `ΔV/I` to `Rs∞`. The GUI then
multiplies that reported value by `F`; it does not apply `π/ln 2` again.

---

## 10. Checklist

### 10.1 Pre-Assembly
- [ ] Arduino Nano 33 IoT blinks and connects to PC.
- [ ] ADS1220 pin headers soldered.
- [ ] BAT54A/C SOT23→DIP soldered accurately.
- [ ] Confirm Resistor bands (68.1Ω, 681Ω, 100Ω, 1kΩ, 10Ω).

### 10.2 Post-Assembly Final Eval
- [ ] Measure a standard known resistor to verify absolute accuracy.
- [ ] Measure an ITO sample (Expect <5% repeatability variance).
- [ ] Current Reversal confirms `V_fwd ≈ -V_rev`.

### 10.3 Flux Cleaning (Critical!)
> [!CAUTION]
> To prevent nano-ampere leakage currents spanning across the stripboard, you MUST clean all flux.

- [ ] Use IPA (Isopropyl Alcohol) and a stiff ESD brush to aggressively scrub the back of the soldered board.

---

## 📚 References

- [ADS1220 Datasheet (TI)](https://www.ti.com/product/ADS1220)
- [LM334 Datasheet (TI)](https://www.ti.com/product/LM334)
- [BAT54 Datasheet (ON Semi)](https://www.onsemi.com/products/discrete-power-modules/schottky-diodes/bat54a)
- [SEMI MF84 - Four-Point Probe Standard](https://store.semi.org/products/mf08400-semi-mf84)
- Smits, F.M. "Measurement of Sheet Resistivities with the Four-Point Probe" Bell System Technical Journal, 1958

---

> **Next Steps**: Having digested this master overview, proceed with the actual build by strictly following **`analog_wiring_guide.md`** and **`movement_implementation_guide.md`**.

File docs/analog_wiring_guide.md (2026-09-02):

# P4PP - Adafruit Perma-Proto (1606) Master Wiring Guide

> **Target Board**: Adafruit Perma-Proto Half-Size (30 Columns)
> The internal connection structure is identical to a standard breadboard. Follow the **Master Chessboard Layout** below to place and solder components, and the entire circuit will be perfectly assembled.

## 0. Understanding the Perma-Proto Board Structure
- **Top & Bottom Power Rails**: The long horizontal red (+) and blue (-) pads.
- **Central Component Area**: Vertical 5-hole groups (a-b-c-d-e, f-g-h-i-j) forming Rows 1 to 30.
- Looking closely at the actual board's lettering, the **bottom-most hole is usually 'a', the one above it 'e'**, skipping the center gap, and the **top-most hole is 'j'**. (See diagram below)

```text
       1  2  3  4  5    (Column Number, Left to Right)
  (Blue line)  - - - - - - - - - - -  ← Top Blue Line (-)
  (Red line)   + + + + + + + + + + +  ← Top Red Line (+)
        ──────────────── 
      j o  o  o  o  o
      i o  o  o  o  o
      h o  o  o  o  o   ← Top Center Group (f~j)
      g o  o  o  o  o
      f o  o  o  o  o
        -------------   ← Center Gap 
      e o  o  o  o  o
      d o  o  o  o  o
      c o  o  o  o  o   ← Bottom Center Group (a~e)
      b o  o  o  o  o
      a o  o  o  o  o
        ──────────────── 
  (Blue line)  - - - - - - - - - - -  ← Bottom Blue Line (-)
  (Red line)   + + + + + + + + + + +  ← Bottom Red Line (+)
```

## 1. Power Rail Allocation (Rules) - ⚡ NEVER BREAK THESE RULES! ⚡

If 12V power enters 3.3V components, they will be instantly destroyed. We must **strictly separate the usage of the top and bottom power rails**.

- **[Top Line] 3.3V ADC / 3.3V Only**:
  1. **Top Blue Line (-)**: `AGND` (Analog Ground - for 3.3V)
  2. **Top Red Line (+)**: `3V3_DIG` (**Pure 3.3V Input from Arduino ONLY**)
- **[Bottom Line] 12V Motor/Relay Only**:
  3. **Bottom Blue Line (-)**: `12V GND` (Ground for Motor/Relay) -> *Only used later in Step 6!*
  4. **Bottom Red Line (+)**: `12V+` (12V Adapter Power) -> *Only used later in Step 6!*

> [!CAUTION]
> **NEVER connect the Arduino to the bottom red line (12V) or put 12V onto the top red line.**
> Similarly, the top `-` rail (AGND) and bottom `-` rail (12V GND) should NOT be directly linked indiscriminately (rely on Star Ground principles).

---

## 🗺️ Master Chessboard Layout (Top-Down View)
The table below illustrates how components are placed across Rows (1~32) of the 60-column Perma-Proto board. (Bottom group is a~e, Top group is f~j)

| Row | Function / Label | [f, g, h, i, j] (Top Group) | [a, b, c, d, e] (Bottom Group) | Connection Notes |
|:---:|:---|:---|:---|:---|
| **1** | **AGND** Extra | **Jumper**(Top Blue➡️1j), **0.1µF**(1i), **1µF**(1h) | 🔴 To **I+** Post (Wire) | GND Node (Jumper Link) |
| **2** | [Empty] | (Capacitor bodies bridge across ⬇️) | ⚫ To **I-** Post (Wire) | Gap for component legs |
| **3** | **3V3_A** | **10Ω**(Top Red➡️3j), **0.1µF**(3i), **1µF**(3h) | (Empty) | Purified 3.3V Node (Step 2) |
| **4** | **IN0** | **IN0 Wire from external BAT54** | **[ADS1220 AIN0]** ➡️ Jumper to Row 8(AIN0) | V+ Sense Line Standby |
| **5** | **IN1** | **IN1 Wire from external BAT54** | **[ADS1220 AIN1]** ➡️ Jumper to Row 9(AIN1) | V- Sense Line Standby |
| **6** | [Input] | **1kΩ**(↑), 🟢 To **V-** Post (Wire) | **1kΩ**(↑), 🔵 To **V+** Post (Wire) | Post Input & Resistor |
| **7** | ADS_Pin1,16 | **[ADS VDD]** ➡️ Jumper to Row 3(3V3_A) | **[ADS AVSS]**(Unused/Internal GND) | 3.3V Power Link |
| **8** | ADS_Pin2,15 | **[ADS DRDY]** ➡️ Arduino D9 | **[ADS AIN0]** ➡️ Jumper to Row 4(IN0) | Data Ready / Sense+ |
| **9** | ADS_Pin3,14 | **[ADS CS]** ➡️ Arduino D10 | **[ADS AIN1]** ➡️ Jumper to Row 5(IN1) | Chip Select / Sense- |
| **10** | ADS_Pin4,13 | **[ADS SCLK]** ➡️ Arduino D13 | **[ADS AIN2]** ➡️ Jumper to Row 21(Shunt+) | Clock / Shunt+ |
| **11** | ADS_Pin5,12 | **[ADS DIN(MOSI)]** ➡️ Arduino D11 | **[ADS AIN3]** ➡️ Jumper to Row 22(Shunt-) | Data IN / Shunt- |
| **12** | ADS_Pin6,11 | **[ADS DOUT(MISO)]** ➡️ Arduino D12 | **[ADS AVDD]**(Unused/Internal VDD) | Data OUT / Analog VDD |
| **13** | ADS_Pin7,10 | **[ADS GND]** ➡️ Jumper to Row 1(GND) | **[ADS REFP]**(Unused) | Main Ground / Ext Ref+ |
| **14** | ADS_Pin8,9 | **[ADS AVSS]**(Unused/Internal GND) | **[ADS REFN]**(Unused) | Analog GND / Ext Ref- |
| **15** | [Empty] | (Empty) | (Empty) | |
| **16** | [Empty] | (Empty) | (Empty) | |
| **17** | [Empty] | (Empty) | (Empty) | |
| **18** | [Empty] | (Empty) | (Empty) | |
| **19** | [Curr Src]| (Empty) | (Empty) | ⬇️ **LM334 Area** ⬇️ |
| **20** | V+ | | **LM334(V+)** ➡️ Jumper to 3V3_A | LM334 Power |
| **21** | R / Sh+ | -> Jumper to Row 10(AIN2) | **LM334(R)**, **Rset(681 ohm default / 68.1 ohm alt)** | Rset Network & Shunt+ |
| **22** | OUT/Sh-| ➡️ Jumper to Row 11(AIN3) | **LM334(V-)**, **Rset**(↑), **100Ω**(↓) | Constant Curr Out & Shunt- |
| **23** | S_COM | | **100Ω**(↑), **DPDT_COM_A**(Jumper wire) | Post 100Ω to Relay |
| **24** | [Empty] | (Empty) | (Empty) | ⬇️ **Relay/12V (Isolated)** ⬇️|
| **25** | RLY_COM| **DPDT COM_B** ➡️ Jumper to AGND | **DPDT COM_A** ⬅️ Jumper from Row 23 | Relay IN terminal |
| **26** | RLY_NO | **DPDT NO_B** ➡️ Jumper to Row 1(I+) | **DPDT NO_A** ➡️ Jumper to Row 2(I-) | Reverse (Cross Swap) |
| **27** | RLY_NC | **DPDT NC_B** ➡️ Jumper to Row 2(I-) | **DPDT NC_A** ➡️ Jumper to Row 1(I+) | Forward (Default) |
| **28** | Coil+ | **1N4148 (Cathode)** | **DPDT Coil 1**, **12V+**(Bot Red) Jumper| Coil Drive Power |
| **29** | Coil- | **1N4148 (Anode)** | **DPDT Coil 2**, **PN2222(Collector)**| Transistor Switching |
| **30** | BASE | **10kΩ**(↓Pull-down) | **PN2222(Base)**, **1kΩ**(↓) | Arduino Signal IN |
| **31** | EMITTER| **1kΩ**(↑)➡️Arduino / **10kΩ**(↑)➡️GND | **PN2222(Emitter)** ➡️ Jumper to 12V GND | TR Ground & Control Net |

*(※ The chessboard diagram above perfectly reflects the pin layout of your CJMCU-1220 module.)*

---

## ♟️ Assembly Progress: Step 1 & 2 - Power Rails & Filters

Initial critical setup steps for those assembling from scratch.

### Step 1: Labeling & Preparation

- [ ] Attach **I+, V+, V-, I-** labels to the panel binding posts.
- [ ] Mark test point locations on the stripboard.
- [ ] Solder BAT54A and BAT54C onto SOT23→DIP adapters. (Mind pin orientation!)

> [!TIP]
> **SOT23 ↔ DIP Adapter Pin Mapping & Soldering Guide**
>
> 1. **BAT54 Orientation (SOT-23)**:
>    Looking down at the part, one side has 1 pin, the opposite side has 2 pins.
>    If you place the 2-pin side on the left, **top-left is Pin 1, bottom-left is Pin 2, and the solo right pin is Pin 3**.
>    ```text
>          ┌───┐
>       1 ─┤   ├─ 3
>          │   │
>       2 ─┤   ├
>          └───┘
>    ```
>    - **BAT54A**: pin1=Cathode1, pin2=Cathode2, pin3=Common Anode
>    - **BAT54C**: pin1=Anode1, pin2=Anode2, pin3=Common Cathode
>    
> 2. **DIP Adapter Board Numbering**:
>    - The adapter has 3 small SOT23 surface pads.
>    - The through-holes (DIP pins) corresponding to pads 1, 2, and 3 are often unlabeled.
>    - **Mandatory Pre-solder Step**: Use a multimeter in **Continuity mode (beep)** to map which through-hole connects to SOT23 pad 1, 2, and 3.
>    - Once identified, **write 1, 2, 3 next to the holes with a sharpie** to avoid confusion later.
>
> 3. **SMD Soldering Tip**:
>    - First, **apply a tiny bit of solder to just ONE** of the 3 pads on the adapter.
>    - Using tweezers, align the component perfectly and melt that single pad to **tack it in place (temporary hold)**.
>    - Check the alignment. If straight, solder the remaining legs.

### Step 2: Power Filter Assembly (Board A & B)

> [!TIP]
> **Wiring Guide (Color & Gauge Recs)**
> - **GND (Ground)**: Always use **Black** or **Blue** wire. (AWG 22 recommended)
> - **3.3V Power**: Always use **Red** or **Orange** wire. (AWG 22 recommended)
> - Use bare **Solid wire** for *short jumpers on the stripboard*, and **Stranded wire** for *connections going off-board or between modules*.

Assembly (Ref. Layout Plot):

1.  **Arduino Power Links (Using wire)**:
    - [ ] `Arduino 3V3` pin ➡️ **Stripboard Column 2 (3V3_DIG)**: Link with **Red** wire
    - [ ] `Arduino GND` pin ➡️ **Stripboard Column 1 (AGND)**: Link with **Black** wire
2.  **Power Filter Components (No wire needed, plug legs directly)**:
    - [ ] **10Ω Resistor ([BOM #28])**: One leg in `Col 2(3V3_DIG)`, the other in `Col 3(3V3_A)`. (Horizontal, e.g., Row 3)
    - [ ] **0.1µF Ceramic Cap ([BOM #30])**: One leg in `Col 1(AGND)`, the other in `Col 3(3V3_A)`. (Horizontal, e.g., Row E)
    - [ ] **1µF Ceramic Cap ([BOM #29])**: Similarly, connect between `Col 1(AGND)` and `Col 3(3V3_A)`. (Horizontal, e.g., Row F)

**Verification (Multimeter DC Voltage Mode)**:
```text
1. Plug a USB cable into the Arduino to supply power.
2. Hold the black probe (COM) firmly on 'Col 1 (AGND)':
   - Touch red probe to 'Col 2 (3V3_DIG)': Expect 3.3V ± 0.1V ✓
   - Touch red probe to 'Col 3 (3V3_A)': Expect 3.3V ± 0.1V ✓ (Should be nearly identical to Col 2)
```

---

## ♟️ Assembly Progress: Step 3 - ADS1220 ADC Module (BOM #2)

Mount the CJMCU-1220 horizontally so it bridges across the center gap of the breadboard according to its specific pinout.

### 3.1 ADS1220 16-Pin Custom Placement

Press the module firmly so its dual-row header pins slide into **[Column d]** and **[Column h]** (or g) holes. (Uses Rows 7 to 14)

```text
       1  2  3  4  5    (Column Number)
         (Top power/filters omitted)
        ---│--│--│------   ← Center Gap 
      ...
(Row 7) h [VDD ] ├───┤ [AVSS] d
(Row 8) h [DRDY] ├───┤ [IN0 ] d
(Row 9) h [ CS ] ├───┤ [IN1 ] d
(Row10) h [SCLK] ├───┤ [IN2 ] d
(Row11) h [DIN ] ├───┤ [IN3 ] d
(Row12) h [DOUT] ├───┤ [AVDD] d
(Row13) h [GND ] ├───┤ [REFP] d
(Row14) h [AVSS] ├───┤ [REFN] d
        ──────────────── 
           ▼  ▼  ▼
```

### 3.2 ADS1220 Power Wiring (Unifying AVDD/AVSS)

This specific module type does NOT internally bridge its analog power (AVDD/AVSS) and digital power (VDD/GND). Therefore, you must make a total of 4 power/ground connections!

1. **Digital Power Connection**:
    - `VDD` Pin (Row 7, top empty hole) ↔ **[Row 3, 3V3_A]** Jumper
    - `GND` Pin (Row 13, top empty hole) ↔ **[Row 1, Main GND]** Jumper
2. **Analog Power Connection (Left-Layout Optimization)**:
    - `AVDD` Pin (Row 12, Left side) ➡️ **`12c` ↔ `3d`** Jumper (Direct short path to purified 3V3_A on Row 3)
    - `AVSS` Pin (Row 7, Left side) ➡️ **`7c` ↔ `1c`** Jumper (Direct short path to purified AGND on Row 1)
*(※ Both VDD and AVDD must receive 3.3V for the internal circuits to fully wake up!)*

### 3.3 Arduino ↔ ADS1220 SPI Communication Wiring

Run long jumper wires from the 'h' column side directly to the **Arduino's digital pins**.

- [x] Module **`SCLK`** Pin (Row 10) ➡️ Arduino **`D13`** `[Yellow Wire]` ✅
- [x] Module **`DIN` (MOSI)** Pin (Row 11) ➡️ Arduino **`D11`** `[Orange Wire]` ✅
- [x] Module **`DOUT` (MISO)** Pin (Row 12) ➡️ Arduino **`D12`** `[White Wire]` ✅
- [x] Module **`CS`** Pin (Row 9) ➡️ Arduino **`D10`** `[Brown Wire]` ✅
- [x] Module **`DRDY`** Pin (Row 8) ➡️ Arduino **`D9`** `[Purple Wire]` ✅

> **Use Stranded wire (Dupont cables) for SPI lines.** Being digital signals, they are resilient to noise and much easier to route long distances to the Arduino.

### 🧪 Verification (Solder/Power Integrity Check)
1. Plug USB into Arduino.
2. Probe **VDD (Row 7)** and **AVDD (Row 12, col d)** with multimeter. Both must show 3.3V.
3. Upload `firmware/debug/ads1220_spi_test/ads1220_spi_test.ino` and open the Serial Monitor.
4. **Write/Read Verification**: Writing `0x6A` to a register and reading it back out successfully proves SPI communication is fully operational.

> [!IMPORTANT]
> **The default register values for the ADS1220 are ALL `0x00`!** (Not `0x08`!)
> Therefore, simply reading a `0x00` does not confirm success.
> You must verify using a **Write → Read Back** pattern.

✅ **2026-02-20 Verification Completed**: `Reg0 = 0x6A` Write/Read match confirmed. SPI comms normal.

---

## ♟️ Assembly Progress: Step 4 - LM334 Constant Current Source

Utilize the empty space beneath the ADS1220 (Rows 20~23) to assemble the LM334 constant current source, the beating heart of resistance measurement. For the default build, start with **681 ohm Rset (~100 uA)** and swap to **68.1 ohm (~1 mA)** only for lower-resistance samples.

### 4.0 Preparation (Check BOM)
Locate these exact components before assembly.
1. **[BOM #3] LM334Z/NOPB (Constant Current Source IC)**:
   - Black half-cylinder (TO-92 Package)
   - Marked `LM334Z`.
2. **[BOM #5] 681 ohm Resistor (0.1% Precision, default Rset)**:
   - Blue body (Precision)
   - Marked `681R` or equivalent precision code.
   - The default Rset for approximately 100 uA test current.
3. **[BOM #4] 68.1 ohm Resistor (0.1% Precision, optional alternate Rset)**:
   - Blue body (Precision)
   - Color bands: **[Blue - Gray - Brown - Gold - Violet]** or marked `68R1`.
   - Swap in when measuring lower-resistance samples that need approximately 1 mA test current.
4. **[BOM #6] 100 ohm Resistor (0.1% Precision, Shunt)**:
   - Blue body (Precision)
   - Color bands: **[Brown - Black - Black - Black - Violet]** or marked `100R`.
   - The shunt resistor used to monitor the *actual* amount of current flowing.

### 4.1 Placement Guide (Bottom Group, Columns a~e)

Use the **bottom-right of the board (Cols a~e)** based on the master layout.

```text
       1  2  3  4  5    (Column Num)
       a  b  c  d  e    (Alpha)
      ...
(Row20) [LM_V+] ───Jumper───► (Row 7, VDD)  ← ⚠️ Row 3 is too crowded, pull from here!
(Row21) [LM_R ] ─────────┐ 
(Row22) [LM_V-] ---+     | (Rset 681 ohm default)
                   │     │ 
(Row23) [S_COM] ───┴─────┴ (100Ω Shunt)
```

### 4.2 Detailed Insertion Order (User-Optimized Layout!)

> 🚨 **Ultra-Precision Note**: With the flat face (printed side) of the half-cylinder LM334 facing you, the pins are 1, 2, and 3 from left to right.

1. **Insert LM334 (#3)**:
   - Pin 1 (V+) ➡️ Hole **20b**
   - Pin 2 (R)  ➡️ Hole **21b**
   - Pin 3 (V-) ➡️ Hole **22b**
2. **Insert Rset Resistor (681 ohm, #5 by default)**:
   - Leg 1 -> Hole **21c**
   - Leg 2 -> Hole **22c**
   > Note: Since you already installed a **[BOM #17] Female Header** into 21c and 22c, you can swap Rset values according to the target material.
   > - **With [BOM #5] 681 ohm (approx. 100 uA, default)**: Rec. Range **1 kOhm/sq ~ 100 kOhm/sq**. (Higher resistance films)
   > - **With [BOM #4] 68.1 ohm (approx. 1 mA)**: Rec. Range **~10 kOhm/sq or lower**. (Low resistance like ITO films)
   > *(This is a safe operating range calculated considering the ADC limit and the LM334's ~2.2V dropout voltage headroom.)*
3. **Insert 100Ω Shunt (#6)**:
   - Leg 1 ➡️ Hole **22d**
   - Leg 2 ➡️ Hole **23d**

*(※ Inserted this way, the components will align vertically in a very neat column.)*

### 4.3 Jumper Wiring (Power & Sensing)

The power routing issue was beautifully solved using the user's **"Row 3 Center Bridge"** idea!

1. **Routing Power to LM334 (Completed)**:
   - Bridge Jumper across the gap **3f ↔ 3e**.
   - Relocated the old AVDD pin to **3d** to free up space.
   - Long Jumper **3a ↔ 20a** drops the power down. (Clean 3.3V successfully delivered to LM334 Pin 20b.)
2. **Connecting ADS1220 Current Monitor Lines (Your Next Task!)**:
   - Now, to actually measure the true current flowing from the source, we run two wires up to the ADC.
   - **Sense Wire 1 (Blue Rec 🔵)**: Drop in **Row 21** (e.g., hole 21e) ➡️ Run up and solder into **Row 10 (MUST be on the 'd' col side!)** (Connects mapping AIN2 / `IN2`)
   - **Sense Wire 2 (Green Rec 🟢)**: Drop in **Row 22** (e.g., hole 22e) ➡️ Run up and solder into **Row 11 (MUST be on the 'd' col side!)** (Connects mapping AIN3 / `IN3`)
   - *(※ The `IN2` and `IN3` labels on the module match perfectly with the `AIN2` and `AIN3` (Analog Input) pins from the datasheet!)*
   - > 🚨 **CRITICAL**: The opposite 'h' column side of Rows 10 and 11 contains the Yellow (SCLK) and Orange (DIN) SPI digital comm lines. These must NEVER touch or mix! The sensing lines must strictly be soldered on the **lower 'd' column side (Analog pin side)**.

### 🧪 4.4 1st Stage Multimeter Verification (Mandatory)
Before powering on the Arduino, use a multimeter to check the solder joints!

1. Set Multimeter to Ω (Resistance) mode.
2. Touch the two probes to the silver solder joints of **Row 21** and **Row 22**.
   - With the default build, screen shows around **~681 ohm**.
   - If you intentionally installed the low-resistance option, screen shows around **~68.1 ohm** (67.5 ~ 68.5).
3. Now, probe **Row 22** and **Row 23**.
   - ➡️ Screen shows around **~100Ω** (99.5 ~ 100.5) = Success!

---

## ♟️ Assembly Progress: Step 5 - BAT54 Input Protection (Board B Finalization)

Since the analog board's (Board B) space from Rows 25~31 is empty, we build a dual-clamping Zener protection circuit here to clamp any over-voltages coming from the probe's micro-voltages (`V+`, `V-`) before they hit the delicate ADC.
We create an invincible shield utilizing the user's combination idea: **BAT54A(Common Anode) + BAT54C(Common Cathode)**.

### 5.1 Essential Bridges (Crossing the Center Gap)
To utilize the purified power (Rows 1 and 3) on the left side (a~e) of the board, add bridge jumpers.
- **[3.3V_A Bridge]**: Jumper `3e` ↔ `3f` (Likely already done)
- **[AGND Bridge]**: Jumper `1e` ↔ `1f` (New addition!)

### 5.2 Component Insertion (SOT-23 Modules)
Insert the two modules into the right side (f~j) in a zig-zag pattern and hook up power.

1. **Insert BAT54A (`Rows 25~27 Area`)**:
   - `27f`: Pin 1 (Cathode 1) ➡️ [Future **V+ Channel**]
   - `25f`: Pin 2 (Cathode 2) ➡️ [Future **V- Channel**]
   - `26e`: Pin 3 (Common Anode) ➡️ Jumper to **`1d` (Purified AGND)**!

2. **Insert BAT54C (`Rows 29~31 Area`)**:
   - `31f`: Pin 1 (Anode 1) ➡️ [Partner for V+ at 27f]
   - `29f`: Pin 2 (Anode 2) ➡️ [Partner for V- at 25f]
   - `30c`: Pin 3 (Common Cathode) ➡️ Jumper to **`3c` (Purified 3.3V_A)**!

### 5.3 Creating the Perfect 1kΩ Input Terminals (Using Rows 35, 37)
> 🌟 **[Full-Board Layout Optimization]** The empty bottom-right space (Rows 35~37) becomes a dedicated terminal zone solely for probe sensing input and the 1kΩ defensive line.

- **[V- Channel Defense Line (Row 35)]**:
  1. Insert external Orange (V-) probe wire down into **`35a`** (Later).
  2. Jumper the **1kΩ resistor** across the center gap, dropping legs into **`35c` and `35i`**.
  3. Send the filtered, safe voltage up to the diode channel via vertical jumper **`35j` ↔ `25j`**.
- **[V+ Channel Defense Line (Row 37)]**:
  1. Insert external Purple (V+) probe wire down into **`37a`** (Later).
  2. Jumper the **1kΩ resistor** across the center gap, dropping legs into **`37c` and `37i`**.
  3. Send the filtered, safe voltage up to the diode channel via vertical jumper **`37j` ↔ `27j`**.

### 5.4 Binding Diode Pairs and Sending to ADC
Finally, we bind the now-safe voltages from the diode zone (Rows 25~31) and pipe them up to the ADC.

- **[Bind Diode Bridges]**: Jumper `31g` ↔ `27g` (V+ Pair), `29g` ↔ `25g` (V- Pair)
- **[Pipe to ADC]**: Long jumper from protected terminal **`27h`** ➡️ Up-left to **`8b` (AIN0)**. Long jumper from terminal **`25h`** ➡️ Up-left to **`9b` (AIN1)**.

> 🎉 **With this, 100% of the soldering for the 3.3V Analog Base Board (Board B) is complete!** 
> It is highly recommended to designate one extra zone to ground the silver shield wires from the external probe later.
> - **[Dedicated Shield Zone (e.g., Row 36)]**: Run one long jumper from the left AGND (Row 1 Blue or 1d) to **`36c`**. Later, twist the V+ and V- shield wires together and plug them into **`36a` or `36b`**, routing noise immediately into the ground away from the board!

---

## ♟️ Assembly Progress: Step 6 - DPDT Relay Drive Circuit (Independent Board!)

> 🌟 **[New Architecture Deployed]** To maximize noise isolation and system stability, from here on out we abandon the old analog breadboard and assemble independently on a **completely new breadboard or perfboard (Board C: 12V Switching Board)**!

This is a 12V Relay switching circuit designed to swap the direction of the 1mA constant current source back and forth (Reversal) into the sample's I+ and I- terminals. We utilize a **PN2222A Transistor** so the weak 3.3V digital signal from the Arduino can reliably flick the beefy 12V relay on and off.

### 6.0 Prep List
1. **[BOM #7] DPDT Relay (12V)** (Panasonic TQ2-12V / 255-1002-5-ND)
2. **[BOM #8] PN2222A Transistor** (NPN, TO-92 Package)
3. **[BOM #9] 1N4148 Diode** (Glass tube type, Black stripe is Cathode)
4. **[BOM #10] 1kΩ Resistor x 2** (Base protection and pull-down)
5. **[BOM #14, #15] 12V SMPS Wall Adapter** (Isolated fresh power source)
6. **[BOM #25] DC Barrel Jack (Panel Mount)** (External power connector)
7. **[BOM #26, #27] Inline blade fuse holder & 5A fuse** (Mandatory safety and fire prevention)

### 6.1 Independent Board (Board C) Insertion Sequence

Grab any breadboard and wire exactly according to these principles. (Row numbers are arbitrary, place freely.)

1. **Place PN2222A Transistor**:
   - Looking face-on at the flat side, pins from left to right are **E, B, C**.
2. **Connect 1N4148 Flyback Diode**:
   - Wire the diode in parallel across the two Relay Coil pins.
   - ⚠️ **Direction Check**: The diode's **Black Stripe (Cathode)** MUST connect to the 12V(+) power side. The stripeless side (Anode) connects to the Transistor's C (Collector).
3. **Connect Two 1kΩ Resistors**:
   - **Base Resistor**: Arduino Control Signal ➡️ 1kΩ Resistor ➡️ Transistor B (Base) pin.
   - **Pull-down Resistor**: Transistor B (Base) pin ➡️ 1kΩ Resistor ➡️ 12V Ground (GND).
4. **Transistor Power/Ground**:
   - Transistor E (Emitter) pin ➡️ 12V Ground (GND).
   - Transistor C (Collector) pin ➡️ Diode (Anode) and one side of the Relay Coil.
5. **Relay Power**:
   - Diode Black Stripe (Cathode) side Coil pin ➡️ External 12V(+) Power Source.

### 6.2 💎 3-Board Core Interface Wiring (Crucial)

These are the 3 "lifeline" wires linking all three independently functioning boards.

1. **[Common GND]**:
   - Board A (Arduino) GND ➡️ **MUST** be inextricably tied via a single wire to Board C (Relay Board)'s 12V GND rail.
2. **[Control Signal]**:
   - Board A (Arduino) Control Pin (e.g., `D8`) ➡️ Tip of Board C's 1kΩ Base resistor.
3. **[1mA Current Supply]**:
   - Board B (Analog Board)'s "Row 23 (End of 100Ω, S_COM)" ➡️ Long jumper connecting directly to the **COM A pin** on the Relay body on Board C.

---

## ♟️ Assembly Progress: Step 7 - 4-Point Probe Final Connection 

Once all circuits and panel assembly are finished, final step is directly terminating the actual **Signatone 4-Point Probe Head's banana plugs (or terminal wires) to the panel**.

### 7.1 Verify 4-Point Probe Pin Arrangement
The 4 pins of a Signatone probe head (especially SP4 series) are arranged linearly. (Pins 1, 2, 3, 4 from the left). Following standard wiring norms:

*   **Pin 1 (Outer edge)** ➡️ **I+ (Current Positive, Red Post)**
*   **Pin 2 (Inner)** ➡️ **V+ (Voltage Positive, Blue Post)**
*   **Pin 3 (Inner)** ➡️ **V- (Voltage Negative, Green Post)**
*   **Pin 4 (Outer edge)** ➡️ **I- (Current Negative, Black Post)**

*(If your specific probe cable colors differ, absolutely verify which tip matches which cable end using a multimeter's continuity mode.)*

### 7.2 Binding Post Connection Method
1. Fully loosen the nuts (screw heads) of the binding posts mounted on the panel by turning them counter-clockwise.
2. Insert the probe cable's terminal pin (or bare stripped wire) deeply into the lateral cross-hole exposed in the metal post shaft.
   *(If using Banana Plugs, ignore the screw entirely and just firmly stab the plug directly into the hole on the front face of the post.)*
3. Twist the nut tightly clockwise to secure. If this connection is loose or flimsy, it is the #1 cause of wildly jumping resistance values.

> 🎉 **Hardware and Wiring Assembly Complete!** Now prepare your sample, upload the code to your Arduino, and commence real-world measurements! You now possess a setup capable of the most ideal and highly precise electrical hardware measurements.

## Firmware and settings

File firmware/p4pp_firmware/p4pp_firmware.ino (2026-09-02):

#include <AccelStepper.h>
#include <SPI.h>

// -----------------------------------------------------------------------------
// Pin Definitions (Arduino Nano 33 IoT)
// -----------------------------------------------------------------------------
// ADS1220 SPI
const int ADS1220_CS_PIN = 10;
const int ADS1220_DRDY_PIN = 9;

// Relay Control
const int RELAY_PIN = 2; // Digital pin to control the DPDT relay (PN2222A base)

// Stepper Motor & Limit Switch
const int ROT_STEP_PIN = 3;
const int ROT_DIR_PIN = 4;
const int LIN_STEP_PIN = 5;
const int LIN_DIR_PIN = 6;
const int LIMIT_SW_LIN_PIN = 7;
const int LIMIT_SW_ROT_PIN = 8;
const int ROT_EN_PIN = A1; // Pull LOW to enable Rotation Driver
const int LIN_EN_PIN = A0; // Pull LOW to enable Linear Driver

AccelStepper rotMotor(AccelStepper::DRIVER, ROT_STEP_PIN, ROT_DIR_PIN);
AccelStepper linMotor(AccelStepper::DRIVER, LIN_STEP_PIN, LIN_DIR_PIN);

// Movement Debugging (set true only when debugging)
const bool DEBUG_MOVEMENT = false;

// -----------------------------------------------------------------------------
// Constants & Settings
// -----------------------------------------------------------------------------
// ADS1220 Commands
const uint8_t RESET_CMD = 0x06;
const uint8_t START_CMD = 0x08;
const uint8_t WREG_CMD = 0x40;
const uint8_t RREG_CMD = 0x20;
const uint8_t RDATA_CMD = 0x10;

// Relay States
const bool RELAY_FORWARD = LOW;
const bool RELAY_REVERSE = HIGH;

// Measurement Settings
const int SETTLING_TIME_MS =
    100; // Wait time after switching relay before taking a reading
const float MIN_VALID_CURRENT_MA = 0.005f; // Supports 681-ohm (~100 uA) mode
const long HOMING_MAX_STEPS = 30000;
const int LIN_HOME_CLEAR_STEPS = 800;         // After first switch hit
const int LIN_HOME_FINAL_BACKOFF_STEPS = 250; // After second switch hit
const int ROT_HOME_CLEAR_STEPS = 200;         // After first switch hit
const int ROT_HOME_FINAL_BACKOFF_STEPS = 70;  // After second switch hit
// Motion conversion baseline (17HS08-1004S + TMC2209 default 1/8 microstep)
const float ROT_STEPS_PER_DEG = 4.444444f; // 400 steps ~= 90 deg
const float LIN_STEPS_PER_MM = 200.0f;     // 8 mm lead, 4-start screw

// ADS1220 MUX/Gain settings used in measurement
const uint8_t ADS_MUX_CURRENT = 0x50;
const uint8_t ADS_MUX_VOLTAGE = 0x00;
const uint8_t ADS_GAIN_CURRENT = 0;
const uint8_t ADS_GAIN_VOLTAGE = 2;

void setup() {
  Serial.begin(115200);
  while (!Serial && millis() < 3000) {
  } // Wait up to 3 seconds for Serial

  // Initialize Pins
  pinMode(ADS1220_CS_PIN, OUTPUT);
  digitalWrite(ADS1220_CS_PIN, HIGH);
  pinMode(ADS1220_DRDY_PIN, INPUT_PULLUP);

  pinMode(RELAY_PIN, OUTPUT);
  digitalWrite(RELAY_PIN, RELAY_FORWARD); // Start in Forward direction

  pinMode(LIMIT_SW_LIN_PIN, INPUT_PULLUP);
  pinMode(LIMIT_SW_ROT_PIN, INPUT_PULLUP);

  pinMode(ROT_EN_PIN, OUTPUT);
  digitalWrite(ROT_EN_PIN, LOW); // Enable rot driver by default
  pinMode(LIN_EN_PIN, OUTPUT);
  digitalWrite(LIN_EN_PIN, LOW); // Enable lin driver by default

  // Stepper Initialization
  rotMotor.setMaxSpeed(1000.0);
  rotMotor.setAcceleration(500.0);

  linMotor.setMaxSpeed(1000.0);
  linMotor.setAcceleration(500.0);

  // Initialize SPI
  SPI.begin();

  Serial.println(F("\n--- P4PP Firmware Starting ---"));

  // Initialize ADS1220
  resetADS1220();
  delay(10);

  // Configure Registers for P4PP operation
  configADS1220();

  Serial.println(F("System Ready."));
}

void setMuxAndGain(uint8_t mux, uint8_t gain, bool bypass_pga) {
  uint8_t reg0_val = mux | (gain << 1) | (bypass_pga ? 0x01 : 0x00);
  writeRegister(0x00, reg0_val);
  delay(5); // Allow internal MUX to settle
}

void dbgPrint(const __FlashStringHelper *label, int value) {
  if (!DEBUG_MOVEMENT)
    return;
  Serial.print(label);
  Serial.println(value);
}

bool parseOneInt(const String &cmd, int &a) {
  int firstSpace = cmd.indexOf(' ');
  if (firstSpace < 0)
    return false;
  a = cmd.substring(firstSpace + 1).toInt();
  return true;
}

bool parseTwoInts(const String &cmd, int &a, int &b) {
  int firstSpace = cmd.indexOf(' ');
  if (firstSpace < 0)
    return false;
  int secondSpace = cmd.indexOf(' ', firstSpace + 1);
  if (secondSpace < 0)
    return false;
  a = cmd.substring(firstSpace + 1, secondSpace).toInt();
  b = cmd.substring(secondSpace + 1).toInt();
  return true;
}

int getSampleCount(const String &cmd, int defaultCount) {
  int value = defaultCount;
  int firstSpace = cmd.indexOf(' ');
  if (firstSpace >= 0) {
    value = cmd.substring(firstSpace + 1).toInt();
  }
  if (value < 1)
    value = 1;
  if (value > 1000)
    value = 1000;
  return value;
}

void setDriverEnable(int enPin, bool enable) {
  // enable=true -> LOW, enable=false -> HIGH
  digitalWrite(enPin, enable ? LOW : HIGH);
}

void parseCommand(String cmd) {
  if (cmd.equals("MEASURE")) {
    executeMeasurement();
  } else if (cmd.equals("HOME_LIN")) {
    homeLinearStepper();
  } else if (cmd.equals("HOME_ROT")) {
    homeRotationStepper();
  } else if (cmd.startsWith("MOVE_LIN ")) {
    long target = cmd.substring(9).toInt();
    linMotor.moveTo(target);
    dbgPrint(F("DBG MOVE_LIN DIR pin: "), digitalRead(LIN_DIR_PIN));
    Serial.print(F("OK LIN_TARGET: "));
    Serial.println(target);
  } else if (cmd.startsWith("MOVE_ROT ")) {
    long target = cmd.substring(9).toInt();
    rotMotor.moveTo(target);
    Serial.print(F("OK ROT_TARGET: "));
    Serial.println(target);
  } else if (cmd.equals("DBG_LIMIT")) {
    dbgPrint(F("DBG LIMIT_LIN: "), digitalRead(LIMIT_SW_LIN_PIN));
    dbgPrint(F("DBG LIMIT_ROT: "), digitalRead(LIMIT_SW_ROT_PIN));
  } else if (cmd.equals("DBG_DIR")) {
    dbgPrint(F("DBG DIR_LIN: "), digitalRead(LIN_DIR_PIN));
    dbgPrint(F("DBG DIR_ROT: "), digitalRead(ROT_DIR_PIN));
  } else if (cmd.startsWith("SET_LIN_DIR ")) {
    int val = 0;
    if (!parseOneInt(cmd, val)) {
      Serial.println(F("ERR SET_LIN_DIR needs 0/1"));
      return;
    }
    digitalWrite(LIN_DIR_PIN, val ? HIGH : LOW);
    dbgPrint(F("DBG LIN_DIR set: "), digitalRead(LIN_DIR_PIN));
  } else if (cmd.startsWith("SET_ROT_DIR ")) {
    int val = 0;
    if (!parseOneInt(cmd, val)) {
      Serial.println(F("ERR SET_ROT_DIR needs 0/1"));
      return;
    }
    digitalWrite(ROT_DIR_PIN, val ? HIGH : LOW);
    dbgPrint(F("DBG ROT_DIR set: "), digitalRead(ROT_DIR_PIN));
  } else if (cmd.startsWith("EN_LIN ")) {
    int val = 0;
    if (!parseOneInt(cmd, val)) {
      Serial.println(F("ERR EN_LIN needs 0/1"));
      return;
    }
    setDriverEnable(LIN_EN_PIN, val != 0);
    dbgPrint(F("DBG LIN_EN pin: "), digitalRead(LIN_EN_PIN));
  } else if (cmd.startsWith("EN_ROT ")) {
    int val = 0;
    if (!parseOneInt(cmd, val)) {
      Serial.println(F("ERR EN_ROT needs 0/1"));
      return;
    }
    setDriverEnable(ROT_EN_PIN, val != 0);
    dbgPrint(F("DBG ROT_EN pin: "), digitalRead(ROT_EN_PIN));
  } else if (cmd.startsWith("STEP_LIN ")) {
    int steps = 0;
    int delayUs = 0;
    if (!parseTwoInts(cmd, steps, delayUs)) {
      Serial.println(F("ERR STEP_LIN needs <steps> <delay_us>"));
      return;
    }
    steps = abs(steps);
    for (int i = 0; i < steps; i++) {
      manualStep(LIN_STEP_PIN, (unsigned int)delayUs);
    }
    Serial.print(F("OK STEP_LIN "));
    Serial.println(steps);
  } else if (cmd.startsWith("STEP_ROT ")) {
    int steps = 0;
    int delayUs = 0;
    if (!parseTwoInts(cmd, steps, delayUs)) {
      Serial.println(F("ERR STEP_ROT needs <steps> <delay_us>"));
      return;
    }
    steps = abs(steps);
    for (int i = 0; i < steps; i++) {
      manualStep(ROT_STEP_PIN, (unsigned int)delayUs);
    }
    Serial.print(F("OK STEP_ROT "));
    Serial.println(steps);
  } else if (cmd.equals("ADS_REG_DUMP")) {
    dumpADS1220Registers();
    Serial.println(F("OK ADS_REG_DUMP"));
  } else if (cmd.startsWith("ADC_RAW_CURR")) {
    int n = getSampleCount(cmd, 1);
    setMuxAndGain(ADS_MUX_CURRENT, ADS_GAIN_CURRENT, true);
    for (int i = 0; i < n; i++) {
      int32_t raw = readADC();
      Serial.print(F("RAW_CURR["));
      Serial.print(i);
      Serial.print(F("]: "));
      Serial.println(raw);
    }
    Serial.println(F("OK ADC_RAW_CURR"));
  } else if (cmd.startsWith("ADC_RAW_VOLT")) {
    int n = getSampleCount(cmd, 1);
    setMuxAndGain(ADS_MUX_VOLTAGE, ADS_GAIN_VOLTAGE, true);
    for (int i = 0; i < n; i++) {
      int32_t raw = readADC();
      Serial.print(F("RAW_VOLT["));
      Serial.print(i);
      Serial.print(F("]: "));
      Serial.println(raw);
    }
    Serial.println(F("OK ADC_RAW_VOLT"));
  } else if (cmd.startsWith("ADC_RAW_BOTH")) {
    int n = getSampleCount(cmd, 1);
    for (int i = 0; i < n; i++) {
      setMuxAndGain(ADS_MUX_CURRENT, ADS_GAIN_CURRENT, true);
      int32_t rawCurr = readADC();
      setMuxAndGain(ADS_MUX_VOLTAGE, ADS_GAIN_VOLTAGE, true);
      int32_t rawVolt = readADC();
      Serial.print(F("RAW_BOTH["));
      Serial.print(i);
      Serial.print(F("] I: "));
      Serial.print(rawCurr);
      Serial.print(F(" V: "));
      Serial.println(rawVolt);
    }
    Serial.println(F("OK ADC_RAW_BOTH"));
  } else if (cmd.startsWith("MEASURE_N")) {
    int n = getSampleCount(cmd, 5);
    executeMeasurementMulti(n);
  } else if (cmd.startsWith("MEASURE_DBG")) {
    int n = getSampleCount(cmd, 4);
    executeMeasurementDebug(n);
  } else if (cmd.equals("RELAY_FWD")) {
    digitalWrite(RELAY_PIN, RELAY_FORWARD);
    Serial.println(F("OK RELAY_FWD"));
  } else if (cmd.equals("RELAY_REV")) {
    digitalWrite(RELAY_PIN, RELAY_REVERSE);
    Serial.println(F("OK RELAY_REV"));
  } else if (cmd.equals("GET_POS")) {
    Serial.print(F("POS LIN: "));
    Serial.print(linMotor.currentPosition());
    Serial.print(F(" ROT: "));
    Serial.println(rotMotor.currentPosition());
  } else if (cmd.equals("ZERO")) {
    linMotor.setCurrentPosition(0);
    rotMotor.setCurrentPosition(0);
    Serial.println(F("OK ZEROED"));
  } else if (cmd.equals("STATUS")) {
    Serial.println(F("OK READY"));
  } else {
    Serial.print(F("ERR Unknown command: "));
    Serial.println(cmd);
  }
}

// Helper: pulse the STEP pin manually at a given interval
void manualStep(int stepPin, unsigned int stepDelayUs) {
  digitalWrite(stepPin, HIGH);
  delayMicroseconds(2);
  digitalWrite(stepPin, LOW);
  delayMicroseconds(stepDelayUs);
}

void homeLinearStepper() {
  Serial.println(F("HOMING_LIN_START"));
  dbgPrint(F("DBG LIMIT_LIN initial: "), digitalRead(LIMIT_SW_LIN_PIN));
  dbgPrint(F("DBG LIN_DIR initial: "), digitalRead(LIN_DIR_PIN));

  // Confirmed baseline: LIN DIR=1 is forward, so homing must use DIR=0.
  const int HOMING_DIR = LOW;
  const int RETREAT_DIR = HIGH;
  dbgPrint(F("DBG HOMING_DIR: "), HOMING_DIR);

  // If already pressed, back off first
  if (digitalRead(LIMIT_SW_LIN_PIN) == LOW) {
    digitalWrite(LIN_DIR_PIN, RETREAT_DIR);
    dbgPrint(F("DBG LIN_DIR set RETREAT_DIR: "), RETREAT_DIR);
    while (digitalRead(LIMIT_SW_LIN_PIN) == LOW) {
      manualStep(LIN_STEP_PIN, 1500);
    }
    // Move a bit more to clear the switch
    for (int i = 0; i < 400; i++)
      manualStep(LIN_STEP_PIN, 1500);
  }

  // 1. Move towards switch - FAST
  digitalWrite(LIN_DIR_PIN, HOMING_DIR);
  dbgPrint(F("DBG LIN_DIR set HOMING_DIR: "), HOMING_DIR);
  long seekSteps = 0;
  while (digitalRead(LIMIT_SW_LIN_PIN) == HIGH) {
    if (++seekSteps > HOMING_MAX_STEPS) {
      Serial.println(F("ERR HOME_LIN seek timeout"));
      return;
    }
    manualStep(LIN_STEP_PIN, 800);
  }

  // 2. Back off 800 steps
  digitalWrite(LIN_DIR_PIN, RETREAT_DIR);
  for (int i = 0; i < LIN_HOME_CLEAR_STEPS; i++)
    manualStep(LIN_STEP_PIN, 1500);

  // 3. Approach again SLOWLY for precision
  digitalWrite(LIN_DIR_PIN, HOMING_DIR);
  seekSteps = 0;
  while (digitalRead(LIMIT_SW_LIN_PIN) == HIGH) {
    if (++seekSteps > HOMING_MAX_STEPS) {
      Serial.println(F("ERR HOME_LIN refine timeout"));
      return;
    }
    manualStep(LIN_STEP_PIN, 4000);
  }

  // 4. Back off slightly to safe zero
  digitalWrite(LIN_DIR_PIN, RETREAT_DIR);
  for (int i = 0; i < LIN_HOME_FINAL_BACKOFF_STEPS; i++)
    manualStep(LIN_STEP_PIN, 1500);

  // Reset AccelStepper position to 0
  linMotor.setCurrentPosition(0);
  Serial.println(F("OK HOMING_LIN_COMPLETE"));
}

void homeRotationStepper() {
  Serial.println(F("HOMING_ROT_START"));

  // rotMotor has NO setPinsInverted so:
  //   MOVE_ROT 100 (positive) -> DIR pin goes HIGH physically
  //   So homing (opposite) -> DIR pin goes LOW
  const int HOMING_DIR = LOW;   // Opposite of MOVE_ROT positive
  const int RETREAT_DIR = HIGH; // Same as MOVE_ROT positive

  // If already pressed, back off first
  if (digitalRead(LIMIT_SW_ROT_PIN) == LOW) {
    digitalWrite(ROT_DIR_PIN, RETREAT_DIR);
    while (digitalRead(LIMIT_SW_ROT_PIN) == LOW) {
      manualStep(ROT_STEP_PIN, 1500);
    }
    for (int i = 0; i < 400; i++)
      manualStep(ROT_STEP_PIN, 1500);
  }

  // 1. Move towards switch - FAST
  digitalWrite(ROT_DIR_PIN, HOMING_DIR);
  long seekSteps = 0;
  while (digitalRead(LIMIT_SW_ROT_PIN) == HIGH) {
    if (++seekSteps > HOMING_MAX_STEPS) {
      Serial.println(F("ERR HOME_ROT seek timeout"));
      return;
    }
    manualStep(ROT_STEP_PIN, 800);
  }

  // 2. Back off 200 steps
  digitalWrite(ROT_DIR_PIN, RETREAT_DIR);
  for (int i = 0; i < ROT_HOME_CLEAR_STEPS; i++)
    manualStep(ROT_STEP_PIN, 1500);

  // 3. Approach again SLOWLY for precision
  digitalWrite(ROT_DIR_PIN, HOMING_DIR);
  seekSteps = 0;
  while (digitalRead(LIMIT_SW_ROT_PIN) == HIGH) {
    if (++seekSteps > HOMING_MAX_STEPS) {
      Serial.println(F("ERR HOME_ROT refine timeout"));
      return;
    }
    manualStep(ROT_STEP_PIN, 4000);
  }

  // 4. Back off slightly to safe zero
  digitalWrite(ROT_DIR_PIN, RETREAT_DIR);
  for (int i = 0; i < ROT_HOME_FINAL_BACKOFF_STEPS; i++)
    manualStep(ROT_STEP_PIN, 1500);

  // Reset AccelStepper position to 0
  rotMotor.setCurrentPosition(0);
  Serial.println(F("OK HOMING_ROT_COMPLETE"));
}

void loop() {
  // Stepper drivers must be called continuously
  rotMotor.run();
  linMotor.run();

  // Non-blocking serial command interface
  static String inputString = "";
  while (Serial.available() > 0) {
    char inChar = (char)Serial.read();
    if (inChar == '\n' || inChar == '\r') {
      if (inputString.length() > 0) {
        inputString.trim();
        parseCommand(inputString);
        inputString = ""; // Reset for next command
      }
    } else {
      inputString += inChar;
    }
  }
}

void executeMeasurement() {
  int32_t current_fwd = 0, voltage_fwd = 0;
  int32_t current_rev = 0, voltage_rev = 0;

  digitalWrite(RELAY_PIN, RELAY_FORWARD);
  delay(SETTLING_TIME_MS);

  setMuxAndGain(ADS_MUX_CURRENT, ADS_GAIN_CURRENT, true);
  current_fwd = readADC();

  setMuxAndGain(ADS_MUX_VOLTAGE, ADS_GAIN_VOLTAGE, true);
  voltage_fwd = readADC();

  digitalWrite(RELAY_PIN, RELAY_REVERSE);
  delay(SETTLING_TIME_MS);

  setMuxAndGain(ADS_MUX_CURRENT, ADS_GAIN_CURRENT, true);
  current_rev = readADC();

  setMuxAndGain(ADS_MUX_VOLTAGE, ADS_GAIN_VOLTAGE, true);
  voltage_rev = readADC();

  Serial.println(F("--- Delta Cycle Data ---"));

  float i_fwd_mA = ((current_fwd * 2.048) / 8388608.0) * 1000.0 / 100.0;
  float v_fwd_mV =
      (((voltage_fwd * 2.048) / 8388608.0) / 4.0) * 1000.0; // Gain = 4
  float i_rev_mA = ((current_rev * 2.048) / 8388608.0) * 1000.0 / 100.0;
  float v_rev_mV =
      (((voltage_rev * 2.048) / 8388608.0) / 4.0) * 1000.0; // Gain = 4

  Serial.print(F("I_fwd: "));
  Serial.print(i_fwd_mA, 4);
  Serial.println(F(" mA"));
  Serial.print(F("V_fwd: "));
  Serial.print(v_fwd_mV, 4);
  Serial.println(F(" mV"));
  Serial.print(F("I_rev: "));
  Serial.print(i_rev_mA, 4);
  Serial.println(F(" mA"));
  Serial.print(F("V_rev: "));
  Serial.print(v_rev_mV, 4);
  Serial.println(F(" mV"));

  float delta_v_mV = (v_fwd_mV - v_rev_mV) / 2.0;
  // Relay reversal flips shunt polarity, so average current magnitudes.
  float test_i_mA = (fabs(i_fwd_mA) + fabs(i_rev_mA)) / 2.0;

  Serial.println(F("- - - - - - - - - - - - "));
  Serial.print(F("Delta_V: "));
  Serial.print(delta_v_mV, 4);
  Serial.println(F(" mV"));
  Serial.print(F("Test_I:  "));
  Serial.print(test_i_mA, 4);
  Serial.println(F(" mA"));

  if (fabs(test_i_mA) > MIN_VALID_CURRENT_MA) {
    float r_sheet = 4.532 * (delta_v_mV / test_i_mA);
    Serial.print(F("Raw R_sheet: "));
    Serial.print(r_sheet, 4);
    Serial.println(F(" Ohm/sq"));
  }

  Serial.println(F("========================\n"));
  Serial.println(F("OK MEASURE_COMPLETE"));
}

// ---------------------------------------------------------------------------
// Multi-cycle measurement: N complete fwd/rev delta cycles with avg & std
// ---------------------------------------------------------------------------
void executeMeasurementMulti(int cycles) {
  if (cycles < 1)
    cycles = 1;
  if (cycles > 20)
    cycles = 20;

  Serial.print(F("--- Multi-Cycle Measurement (N="));
  Serial.print(cycles);
  Serial.println(F(") ---"));

  float rs_values[20];
  float sum = 0.0;

  for (int c = 0; c < cycles; c++) {
    // Forward
    digitalWrite(RELAY_PIN, RELAY_FORWARD);
    delay(SETTLING_TIME_MS);
    setMuxAndGain(ADS_MUX_CURRENT, ADS_GAIN_CURRENT, true);
    int32_t current_fwd = readADC();
    setMuxAndGain(ADS_MUX_VOLTAGE, ADS_GAIN_VOLTAGE, true);
    int32_t voltage_fwd = readADC();

    // Reverse
    digitalWrite(RELAY_PIN, RELAY_REVERSE);
    delay(SETTLING_TIME_MS);
    setMuxAndGain(ADS_MUX_CURRENT, ADS_GAIN_CURRENT, true);
    int32_t current_rev = readADC();
    setMuxAndGain(ADS_MUX_VOLTAGE, ADS_GAIN_VOLTAGE, true);
    int32_t voltage_rev = readADC();

    float i_fwd = ((current_fwd * 2.048) / 8388608.0) * 1000.0 / 100.0;
    float v_fwd = (((voltage_fwd * 2.048) / 8388608.0) / 4.0) * 1000.0;
    float i_rev = ((current_rev * 2.048) / 8388608.0) * 1000.0 / 100.0;
    float v_rev = (((voltage_rev * 2.048) / 8388608.0) / 4.0) * 1000.0;

    float delta_v = (v_fwd - v_rev) / 2.0;
    // Relay reversal flips shunt polarity, so average current magnitudes.
    float test_i = (fabs(i_fwd) + fabs(i_rev)) / 2.0;

    float rs = 0.0;
    if (fabs(test_i) > MIN_VALID_CURRENT_MA) {
      rs = 4.532 * (delta_v / test_i);
    }
    rs_values[c] = rs;
    sum += rs;

    Serial.print(F("CYCLE:"));
    Serial.print(c + 1);
    Serial.print(F(" Rs:"));
    Serial.println(rs, 4);
  }

  float avg = sum / cycles;

  // Compute std dev
  float sq_sum = 0.0;
  for (int c = 0; c < cycles; c++) {
    float diff = rs_values[c] - avg;
    sq_sum += diff * diff;
  }
  float std_dev = (cycles > 1) ? sqrt(sq_sum / (cycles - 1)) : 0.0;

  Serial.print(F("AVG:"));
  Serial.print(avg, 4);
  Serial.print(F(" STD:"));
  Serial.println(std_dev, 4);

  // Also emit the standard result line for backward compat
  Serial.print(F("Raw R_sheet: "));
  Serial.print(avg, 4);
  Serial.println(F(" Ohm/sq"));

  Serial.println(F("OK MEASURE_COMPLETE"));
}

int32_t readADCAveraged(int samples, int discardFirst) {
  if (samples < 1)
    samples = 1;
  int64_t sum = 0;
  int count = 0;
  for (int i = 0; i < samples + discardFirst; i++) {
    int32_t raw = readADC();
    if (i < discardFirst)
      continue;
    sum += raw;
    count++;
  }
  if (count == 0)
    return 0;
  return (int32_t)(sum / count);
}

void executeMeasurementDebug(int samples) {
  const int discardFirst = 1;

  Serial.println(F("--- MEASURE_DBG START ---"));
  Serial.print(F("DBG samples: "));
  Serial.println(samples);
  Serial.print(F("DBG discard_first: "));
  Serial.println(discardFirst);

  digitalWrite(RELAY_PIN, RELAY_FORWARD);
  delay(SETTLING_TIME_MS);

  setMuxAndGain(ADS_MUX_CURRENT, ADS_GAIN_CURRENT, true);
  int32_t current_fwd = readADCAveraged(samples, discardFirst);
  setMuxAndGain(ADS_MUX_VOLTAGE, ADS_GAIN_VOLTAGE, true);
  int32_t voltage_fwd = readADCAveraged(samples, discardFirst);

  digitalWrite(RELAY_PIN, RELAY_REVERSE);
  delay(SETTLING_TIME_MS);

  setMuxAndGain(ADS_MUX_CURRENT, ADS_GAIN_CURRENT, true);
  int32_t current_rev = readADCAveraged(samples, discardFirst);
  setMuxAndGain(ADS_MUX_VOLTAGE, ADS_GAIN_VOLTAGE, true);
  int32_t voltage_rev = readADCAveraged(samples, discardFirst);

  Serial.print(F("RAW I_fwd: "));
  Serial.println(current_fwd);
  Serial.print(F("RAW V_fwd: "));
  Serial.println(voltage_fwd);
  Serial.print(F("RAW I_rev: "));
  Serial.println(current_rev);
  Serial.print(F("RAW V_rev: "));
  Serial.println(voltage_rev);

  float i_fwd_mA = ((current_fwd * 2.048) / 8388608.0) * 1000.0 / 100.0;
  float v_fwd_mV =
      (((voltage_fwd * 2.048) / 8388608.0) / 4.0) * 1000.0; // Gain = 4
  float i_rev_mA = ((current_rev * 2.048) / 8388608.0) * 1000.0 / 100.0;
  float v_rev_mV =
      (((voltage_rev * 2.048) / 8388608.0) / 4.0) * 1000.0; // Gain = 4

  float delta_v_mV = (v_fwd_mV - v_rev_mV) / 2.0;
  // Relay reversal flips shunt polarity, so average current magnitudes.
  float test_i_mA = (fabs(i_fwd_mA) + fabs(i_rev_mA)) / 2.0;

  Serial.print(F("DBG I_fwd(mA): "));
  Serial.println(i_fwd_mA, 6);
  Serial.print(F("DBG V_fwd(mV): "));
  Serial.println(v_fwd_mV, 6);
  Serial.print(F("DBG I_rev(mA): "));
  Serial.println(i_rev_mA, 6);
  Serial.print(F("DBG V_rev(mV): "));
  Serial.println(v_rev_mV, 6);
  Serial.print(F("DBG Delta_V(mV): "));
  Serial.println(delta_v_mV, 6);
  Serial.print(F("DBG Test_I(mA): "));
  Serial.println(test_i_mA, 6);

  if (fabs(test_i_mA) > MIN_VALID_CURRENT_MA) {
    float r_sheet = 4.532 * (delta_v_mV / test_i_mA);
    Serial.print(F("DBG Raw R_sheet: "));
    Serial.println(r_sheet, 6);
  } else {
    Serial.print(F("DBG Raw R_sheet: skipped (|I| <= "));
    Serial.print(MIN_VALID_CURRENT_MA, 3);
    Serial.println(F("mA)"));
  }

  Serial.println(F("OK MEASURE_DBG"));
}

void resetADS1220() {
  SPI.beginTransaction(SPISettings(100000, MSBFIRST, SPI_MODE1));
  digitalWrite(ADS1220_CS_PIN, LOW);
  delayMicroseconds(1);
  SPI.transfer(RESET_CMD);
  delayMicroseconds(1);
  digitalWrite(ADS1220_CS_PIN, HIGH);
  SPI.endTransaction();
  Serial.println(F("ADS1220 Reset Command Sent."));
}
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

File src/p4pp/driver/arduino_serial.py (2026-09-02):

import serial
import threading
import queue
import time
import logging

logger = logging.getLogger(__name__)


class ArduinoSerial:
    """
    Low-level serial wrapper that continuously reads from the Arduino
    in a background thread to prevent UI freezing.
    """

    CONNECT_RETRIES = 3
    CONNECT_RETRY_DELAY_S = 0.75
    POST_OPEN_SETTLE_S = 2.0

    def __init__(self, port, baud_rate=115200):
        self.port = port
        self.baud_rate = baud_rate
        self._serial = None
        self._rx_queue = queue.Queue()
        self._thread = None
        self._running = False
        self.last_error = None

    def connect(self) -> bool:
        """Opens the serial port and starts the reader thread."""
        self.disconnect()
        self.last_error = None

        last_exc = None
        for attempt in range(1, self.CONNECT_RETRIES + 1):
            try:
                # exclusive=True helps on Windows when a previous handle is sticky.
                self._serial = serial.Serial(
                    port=self.port,
                    baudrate=self.baud_rate,
                    timeout=1,
                    write_timeout=1,
                    exclusive=True,
                )
                # Nano 33 IoT (native USB CDC) soft-resets on DTR assert at open.
                time.sleep(self.POST_OPEN_SETTLE_S)
                try:
                    self._serial.reset_input_buffer()
                    self._serial.reset_output_buffer()
                except Exception:
                    pass

                self._running = True
                self._thread = threading.Thread(
                    target=self._read_loop, name=f"serial-rx-{self.port}", daemon=True
                )
                self._thread.start()
                logger.info(
                    "Connected to Arduino on %s at %s baud (attempt %s).",
                    self.port,
                    self.baud_rate,
                    attempt,
                )
                return True
            except (serial.SerialException, OSError, ValueError) as e:
                last_exc = e
                self.last_error = str(e)
                logger.warning(
                    "Connect attempt %s/%s to %s failed: %s",
                    attempt,
                    self.CONNECT_RETRIES,
                    self.port,
                    e,
                )
                self._force_close_port()
                if attempt < self.CONNECT_RETRIES:
                    time.sleep(self.CONNECT_RETRY_DELAY_S)

        logger.error("Failed to connect to %s after retries: %s", self.port, last_exc)
        return False

    def disconnect(self):
        """Stops the reader thread and closes the serial port."""
        self._running = False
        thread = self._thread
        self._thread = None
        if thread and thread.is_alive():
            thread.join(timeout=1.0)

        self._force_close_port()
        # Drop any stale RX lines so the next session starts clean.
        while not self._rx_queue.empty():
            try:
                self._rx_queue.get_nowait()
            except queue.Empty:
                break

    def _force_close_port(self):
        ser = self._serial
        self._serial = None
        if ser is None:
            return
        try:
            if ser.is_open:
                try:
                    ser.dtr = False
                except Exception:
                    pass
                ser.close()
                logger.info("Disconnected from %s.", self.port)
        except Exception as e:
            logger.warning("Error while closing %s: %s", self.port, e)

    def send_command(self, command: str):
        """Sends a newline-terminated command to the Arduino."""
        if self._serial and self._serial.is_open:
            # Enforce exactly one newline
            cmd_str = command.strip() + "\n"
            self._serial.write(cmd_str.encode("utf-8"))
            logger.debug("TX: %s", cmd_str.strip())
        else:
            logger.warning("Attempted to send command, but serial is not connected.")

    def has_data(self) -> bool:
        """Returns True if there is unread data in the queue."""
        return not self._rx_queue.empty()

    def get_line(self) -> str:
        """Gets a line from the queue if available, otherwise returns empty string."""
        try:
            return self._rx_queue.get_nowait()
        except queue.Empty:
            return ""

    def _read_loop(self):
        """Background thread operation that constantly fills the RX queue."""
        while self._running and self._serial and self._serial.is_open:
            try:
                if self._serial.in_waiting > 0:
                    line = self._serial.readline().decode("utf-8", errors="ignore").strip()
                    if line:
                        logger.debug("RX: %s", line)
                        self._rx_queue.put(line)
                else:
                    time.sleep(0.01)  # Yield to prevent 100% CPU usage
            except serial.SerialException as e:
                logger.error("Serial port error during read: %s", e)
                self._running = False
                break
            except OSError as e:
                logger.error("Serial OS error during read: %s", e)
                self._running = False
                break

        logger.debug("Serial read loop terminated.")
